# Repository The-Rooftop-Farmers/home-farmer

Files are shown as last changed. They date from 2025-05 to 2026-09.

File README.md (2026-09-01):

# Home Farmer Robot

> **Note:** This file has been modified using AI.

The **Home Farmer Robot** is a semi-automatic plant care robot designed to monitor and maintain optimal growing conditions for small-scale indoor farming. Built for the **World Robot Olympiad (WRO)** competition, this project uses an Arduino-controlled gantry system with sensors and a Raspberry Pi web dashboard to automate irrigation, seeding, and environmental monitoring.

> 🌐 **Live Website:** [the-rooftop-farmers.github.io/home-farmer](https://the-rooftop-farmers.github.io/home-farmer)
>
> 📦 **Required Library:** [Operate Library](https://github.com/The-Rooftop-Farmers/Operate-Lib/releases) — install via Arduino IDE (Sketch → Include Library → Add .ZIP Library)

---

## Features

- **3-Axis Gantry System** — X/Y/Z stepper motors with limit-switch homing and position limits (via [Operate Library](https://github.com/The-Rooftop-Farmers/Operate-Lib))
- **Automated Seeding** — Picks seeds from a designated area and plants at 4 predefined positions (or custom coordinates via rotary encoder)
- **Smart Watering** — Measures soil moisture at each plant; waters only when below threshold (40%), re-checks until target (70%) reached
- **Environmental Monitoring** — DHT11 temperature/humidity + soil moisture sensor (analog)
- **Real-Time Clock** — DS1307 RTC for scheduled auto-watering (3 min interval, configurable)
- **LCD Menu Interface** — 20×4 I²C LCD with rotary encoder + button navigation
- **Raspberry Pi Web Dashboard** — Live camera feed (Pi Camera 2), sensor charts (Chart.js), REST API (`/sensors`, `/sensors/history`, `/video`)
- **Alexa/Serial Integration** — Accepts `SEED`, `WATER`, `RESET`, `DHT:` commands over serial
- **Auto-Watering Mode** — Background timer triggers watering cycle independently of menu

---

## Hardware

| Component | Qty | Notes |
|---|-----|---|
| Arduino Mega 2560 (or Uno with port expanders) | 1 | Main controller |
| NEMA 17 Stepper Motors | 3 | X, Y, Z axes |
| A4988 / DRV8825 Stepper Drivers | 3 | One per motor |
| Limit Switches (NO) | 3 | Homing for X, Y, Z |
| Soil Moisture Sensor (capacitive/resistive) | 1 | Analog, connected to A3 |
| DHT11 Temperature/Humidity Sensor | 1 | Digital, pin 27 on Pi (also read via serial from Arduino) |
| DS1307 RTC Module | 1 | I²C (0x68) |
| 20×4 I²C LCD (0x27) | 1 | 4-row display |
| Rotary Encoder (KY-040) | 1 | CLK=A2, DT=A1, SW=A0 |
| Water Pump (5V/12V) + Relay/Transistor | 1 | Pin 12 (Arduino) |
| Servo (SG90/MG996R) | 1 | Seed picker, pin 13 |
| Raspberry Pi 4 + Pi Camera Module 2 | 1 | Web dashboard + camera |
| 3D Printed Frame & Gantry | 1 | See `3D Printing/` |

---

## Pinout (Arduino)

| Function | Pin | Notes |
|---|-----|---|
| Stepper X – Step | 2 | `mot_x.setPin(2, 5)` |
| Stepper X – Dir | 5 | |
| Stepper Y – Step | 3 | `mot_y.setPin(3, 6)` |
| Stepper Y – Dir | 6 | |
| Stepper Z – Step | 4 | `mot_z.setPin(4, 7)` |
| Stepper Z – Dir | 7 | |
| Limit Switch X | 9 | `INPUT_PULLUP` |
| Limit Switch Y | 10 | `INPUT_PULLUP` |
| Limit Switch Z | 11 | `INPUT_PULLUP` |
| Water Pump Relay | 12 | `OUTPUT`, active HIGH |
| Servo (Seed Picker) | 13 | `Servo.attach(13)` |
| Soil Moisture (Analog) | A3 | 0–1023 → mapped to 0–100% |
| Rotary Encoder CLK | A2 | |
| Rotary Encoder DT | A1 | |
| Rotary Encoder SW | A0 | `INPUT_PULLUP` (button) |
| I²C SDA/SCL | 20/21 | LCD (0x27), RTC (0x68) |

---

## Software Architecture

```
┌─────────────────────────────────────────────────────────────┐
│                      ARDUINO (main.ino)                      │
│  ┌──────────────┐ ┌──────────────┐ ┌────────────────────┐  │
│  │ Gantry Control│ │ Sensor Read  │ │ Menu State Machine │  │
│  │ (Operate lib) │ │ (DHT, Moist, │ │ (20 screens, rotary │  │
│  │  Homing, Limits)│ │  RTC)      │ │  encoder + button) │  │
│  └──────┬───────┘ └──────┬───────┘ └─────────┬──────────┘  │
│         │                │                   │             │
│         └────────────────┼───────────────────┘             │
│                          ▼                                  │
│                   Serial (9600) ◄──────────────────────┐    │
└──────────────────────────────────────────────────────────│────┘
                                                           │ USB
                                                           ▼
┌──────────────────────────────────────────────────────────────────┐
│                    RASPBERRY PI (Flask + PiCamera2)               │
│  ┌─────────────┐  ┌─────────────┐  ┌─────────────────────────┐  │
│  │ Serial Bridge│  │ Sensor Sampler│ │   Web Routes (Flask)    │  │
│  │ (MOISTURE:←  │  │ (1 Hz, DHT +  │  │  /          → index.html│  │
│  │  DHT:→)      │  │  Arduino)    │  │  /video     → MJPEG     │  │
│  └─────────────┘  └─────────────┘  │  /sensors   → JSON now    │  │
│                                    │  /sensors/history → JSON  │  │
│                                    └─────────────────────────┘  │
└──────────────────────────────────────────────────────────────────┘
```

**Key Data Flow:**
1. Arduino reads soil moisture (A3) → sends `MOISTURE:<val>\n` every 1 s
2. Pi reads serial, parses moisture, updates global `soil_moisture_value`
3. Pi reads DHT11 locally → sends `DHT:<temp>,<hum>\n` back to Arduino (Arduino displays on LCD)
4. Flask serves `/sensors` (current), `/sensors/history` (last 60 samples), `/video` (MJPEG stream)

---

## Getting Started

### 1. Arduino Firmware

**Dependencies (Arduino IDE → Library Manager):**
- `Operate` — [download ZIP](https://github.com/The-Rooftop-Farmers/Operate-Lib/releases) → Sketch → Include Library → Add .ZIP Library
- `LiquidCrystal_I2C`
- `uRTCLib`
- `DHT sensor library` (Adafruit)
- `Servo` (built-in)

**Upload:**
1. Open `main/main.ino`
2. Select board (Arduino Mega 2560) and port
3. Upload

**Calibration (adjust in code):**
- `xStepsPerCm`, `yStepsPerCm` in `UnitConversion()` — measure your gantry travel per step
- `xOffset`, `halfSquareWidth` — physical offsets
- Soil moisture `map()` ranges (lines 350, 448) — measure dry/wet raw values
- Motor speeds (`setSpeed`), homing speeds, position limits — match your hardware

### 2. Raspberry Pi Dashboard

**Requirements:**
- Raspberry Pi OS (64-bit recommended)
- Python 3.9+
- Pi Camera Module 2 (or USB webcam — modify `main.py`)

**Install:**
```bash
cd "Raspberry Pi Scripts/Web Dashboard"
python3 -m venv .venv
source .venv/bin/activate
pip install -r requirements.txt
# requirements.txt: flask, pyserial, opencv-python, picamera2, Adafruit-DHT
```

**Run:**
```bash
python main.py
# Serves on http://<pi-ip>:4000
```

**Systemd Service (auto-start):**
```ini
# /etc/systemd/system/home-farmer-dashboard.service
[Unit]
Description=Home Farmer Web Dashboard
After=network.target

[Service]
WorkingDirectory=/home/pi/HomeFarmer/Raspberry Pi Scripts/Web Dashboard
ExecStart=/home/pi/HomeFarmer/Raspberry Pi Scripts/Web Dashboard/.venv/bin/python main.py
Restart=always
User=pi

[Install]
WantedBy=multi-user.target
```
```bash
sudo systemctl enable --now home-farmer-dashboard
```

### 3. 3D Printing

STL files in `3D Printing/2024 (v2.4)/Home Farmer All 3D Printed Parts.stl`. Print with:
- Material: PLA or PETG
- Infill: 30–40% (structural parts), 15% (non-structural)
- Layer height: 0.2 mm
- Supports: As needed for overhangs

---

## Menu System (LCD)

| Screen | Function |
|---|---|
| 0/1 | Home — time, date, temp, humidity, menu entry |
| 3 | Info — version, authors, mentor |
| 4 | Main Menu — Plant Seed / Water Plants / Parameters / Exit |
| 5–6 | Plant Seed confirmation |
| 7–11 | Water Plants / Parameters / Exit navigation |
| 12–14 | Seed planting confirmation (Yes/No) |
| 15 | Seeding in progress (homes → seeds 4 positions → homes) |
| 16–18 | Watering confirmation (Yes/No) |
| 19 | Watering in progress (homes → checks 4 positions → homes) |
| 20 | Parameters — live temp/humidity/moisture display |

**Navigation:** Rotary encoder scrolls, button selects. `>` indicator shows cursor.

---

## Serial Commands (for Alexa / Home Assistant / Custom Integrations)

Send via USB serial (9600 baud, newline-terminated):

| Command | Effect |
|---|---|
| `SEED` | Homes all axes, runs seeding sequence (screen 15) |
| `WATER` | Homes all axes, runs watering sequence (screen 19) |
| `RESET` | Software reset (watchdog) |
| `DHT:<temp>,<hum>` | Pi → Arduino: updates displayed temp/humidity |

Example (Python):
```python
import serial
ser = serial.Serial('/dev/ttyACM0', 9600, timeout=1)
ser.write(b'SEED\n')
```

---

## Project Structure

```
Home Farmer/
├── main/
│   └── main.ino              # Arduino firmware (1200+ lines)
├── Raspberry Pi Scripts/
│   └── Web Dashboard/
│       ├── main.py           # Flask + PiCamera2 + serial bridge
│       ├── requirements.txt
│       ├── templates/
│       │   └── index.html    # Dashboard UI (Chart.js)
│       └── static/
│           ├── style.css
│           └── script.js     # Live sensor charts
├── 3D Printing/
│   └── 2024 (v2.4)/
│       └── Home Farmer All 3D Printed Parts.stl
├── Old Code/                 # Early prototypes (reference only)
├── Project Reports/          # WRO competition reports (PDF)
└── README.md                 # This file
```

---

## Troubleshooting

| Symptom | Likely Cause | Fix |
|---|---|-----|
| Motors don't home | Limit switch wiring / `INPUT_PULLUP` logic | Check switches: NO → pin reads LOW when triggered |
| Soil moisture always 0/100 | `map()` range wrong | Measure raw `analogRead(A3)` in air vs water; update `map(min, max, 0, 100)` |
| LCD shows garbage | I²C address wrong | Run I²C scanner; common addresses: 0x27, 0x3F |
| Pi dashboard shows no camera | `picamera2` not configured | `sudo raspi-config` → Interface Options → Camera → Enable |
| Serial `MOISTURE:` not received | Baud mismatch / port wrong | Confirm 9600 baud; `ls /dev/ttyACM*` or `ttyUSB*` |
| Auto-watering doesn't trigger | `autowater` flag false | Set `bool autowater = true;` in code or via menu (not yet exposed) |

---

## Competition History

- **WRO 2024 (v2.4)** — Virtual & Regional rounds — Project reports in `Project Reports/2024/` and `2025/`
- **Team:** The Rooftop Farmers
- **Students:** Vihaan Parlikar, Yogeshwar Deshmukh
- **Mentor:** Malhar Ashtaputre

---

## License

MIT License — see [LICENSE](LICENSE).

---

## Acknowledgements

- [Operate Library](https://github.com/The-Rooftop-Farmers/Operate-Lib) — Stepper motor control with homing/limits
- Original Foliate project (inspiration for modular design)
- World Robot Olympiad community

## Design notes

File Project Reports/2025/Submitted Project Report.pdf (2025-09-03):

# HOME

# WRO Junior Future Innovators

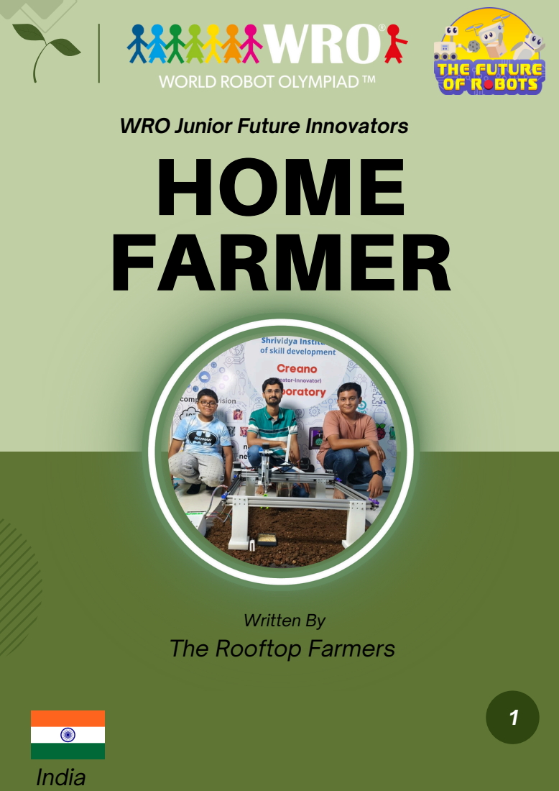
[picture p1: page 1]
FARMER; India

Written By
The Rooftop Farmers

# WRO Junior Future Innovators

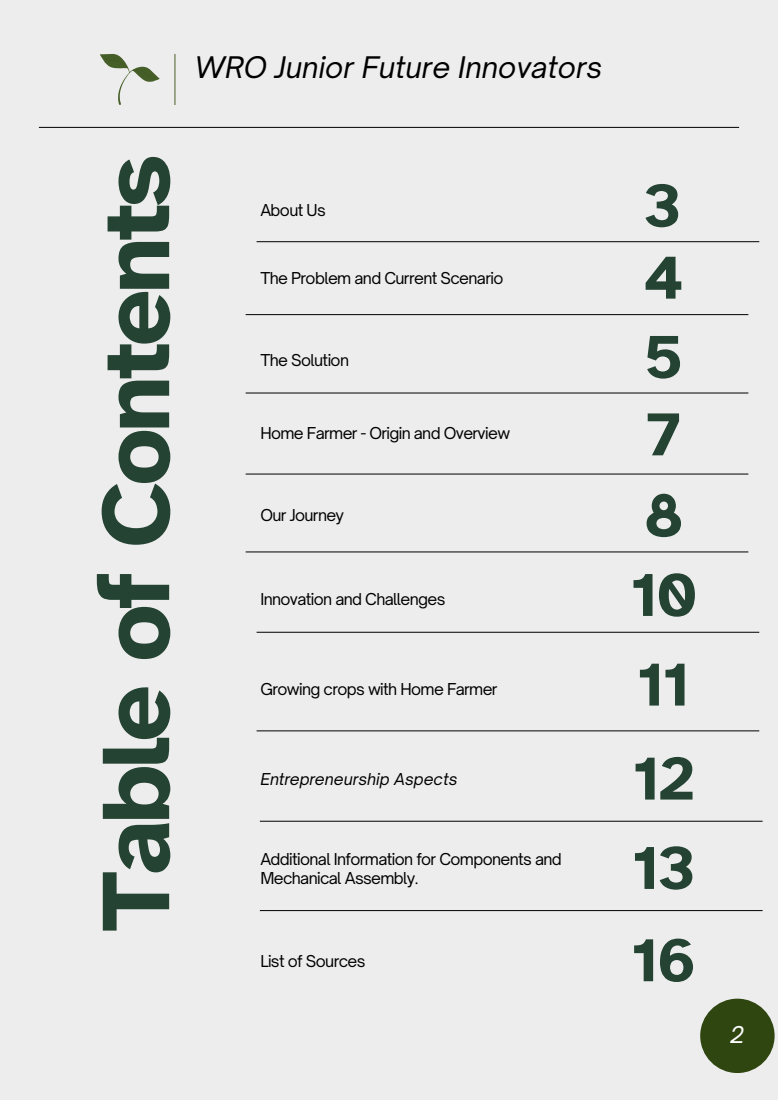
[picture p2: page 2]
About Us; The Problem and Current Scenario; The Solution; Home Farmer - Origin and Overview; Our Journey; Innovation and Challenges; Mechanical Assembly.; Entrepreneurship Aspects

Growing crops with Home Farmer

Additional Information for Components and

List of Sources

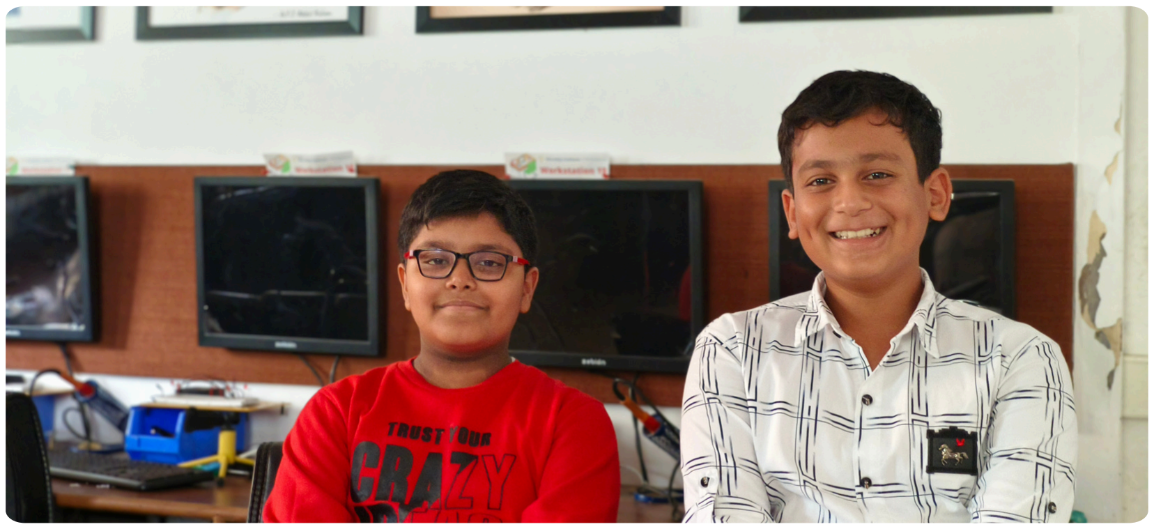
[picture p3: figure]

The Rooftop Farmers, a duo of school students, are on a mission to revolutionize sustainable development through robotics. With a keen interest in environmental conservation, they're making innovative solutions that promise a greener future. These two young minds are tirelessly developing a sustainable robotics project, aiming to safeguard the environment and promote eco-friendly practices. Their dedication, creativity, and passion for sustainability make them a force to be reckoned with, embodying the spirit of youth-driven change in the quest

Picture 1 - Yogeshwar & Vihaan

# ABOUT US

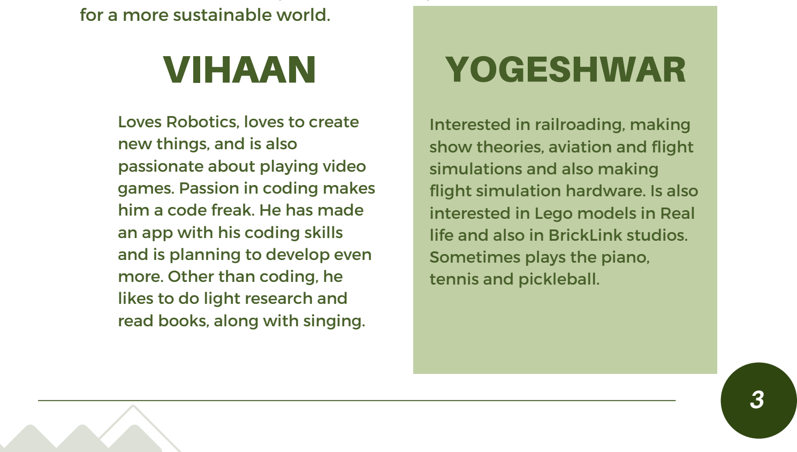
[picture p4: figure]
for a more sustainable world.; Loves Robotics, loves to create new things, and is also passionate about playing video games. Passion in coding makes him a code freak. He has made an app with his coding skills and is planning to develop even more. Other than coding, he likes to do light research and read books, along with singing.; Interested in railroading, making show theories, aviation and flight simulations and also making flight simulation hardware. Is also interested in Lego models in Real life and also in BrickLink studios. Sometimes plays the piano, tennis and pickleball.; VIHAAN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

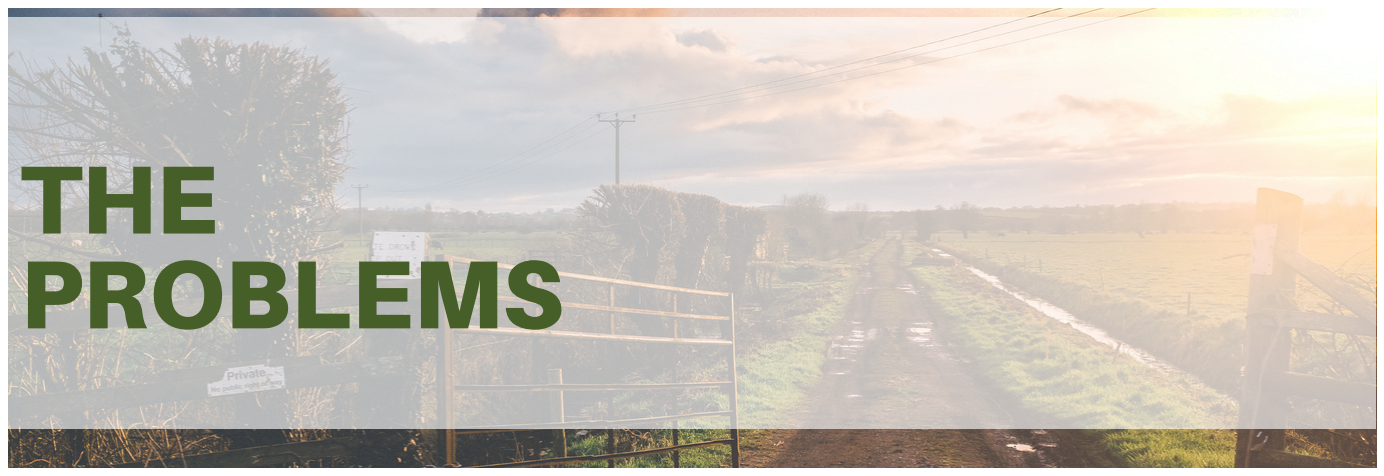
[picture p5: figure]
THE PROBLEMS

The current scene regarding land pollution and soil infertility paints a concerning picture of environmental degradation. As the population grew, farmers started using chemical fertilizers to meet demands. This rampant use of chemical fertilizers has led to soil degradation, reduced fertility, and contamination of groundwater. These practices not only harm the soil but also affect the quality of our food supply. Excessive use of fertilizers contributes to nutrient imbalances in crops, leading to health issues like diseases of the kidneys and liver, and certain cancers in consumers. These adverse effects not only endanger public health but also hinder sustainable development by compromising the long-term viability of agricultural systems and ecosystems, emphasizing the urgent need for eco-friendly farming practices.

## A Brief Description About the Current Scenario

## The Global Warming Effect

Urban food production is challenging due to limited space and busy lifestyles, making traditional gardening difficult.

” The problem matters as
cities face a growing demand for sustainable, self-reliant food production.

## The Urban Challenge

Global warming makes land pollution and soil problems worse. It changes rain and causes droughts or floods, harming soil.

“High
temperatures accelerate soil degradation, making food production more difficult and affecting health and sustainable development. We need to act fast to fix this.

4

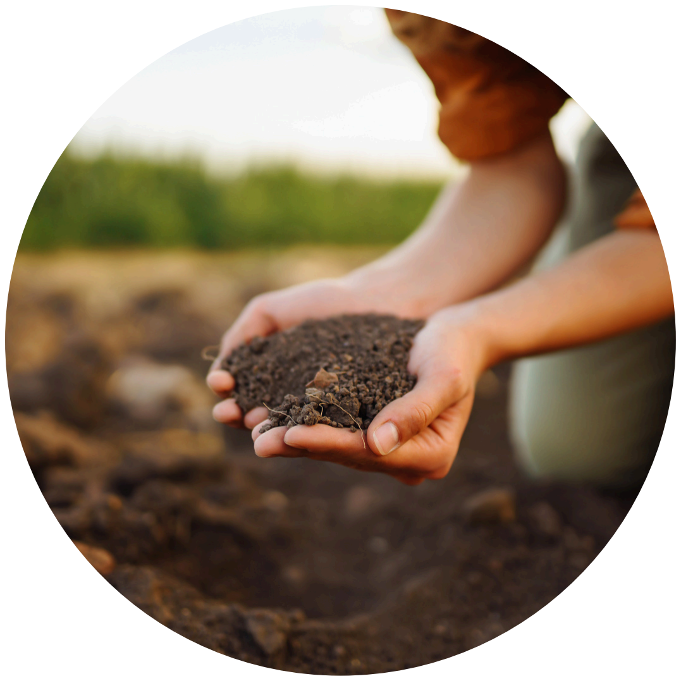
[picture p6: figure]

# THE SOLUTION

Our project, Home Farmer, aims to address the pressing issues of produce being grown with chemical fertilizers, and the growing need for sustainable urban farming. These challenges are critical due to their impact on food safety, environmental health, and sustainable development. Though “Very few people practice home farming because growing organic food at home is challenging and time-consuming.

”
Home farming is uncommon as people find it difficult to produce truly organic food without using chemical fertilizers.

”

## Problem Statement:

We chose this problem because conventional farming practices often contribute to soil degradation and pollution through the heavy use of chemical fertilizers, pesticides, and intensive land cultivation. Urbanization further exacerbates these issues by reducing available arable land and increasing pollution levels.

## Why This Problem

Home Farmer is the robotic solution that we designed to revolutionize farming practices. It is capable of planting seeds, autonomously providing daily water requirements, and monitoring the environment in which the plants are growing. By incorporating sensors and sustainable farming techniques, Home Farmer optimizes resource usage and reduces reliance on harmful chemicals. The solution also reduces the human efforts for farming and makes it easily available at home.

## Robotic Solution

5

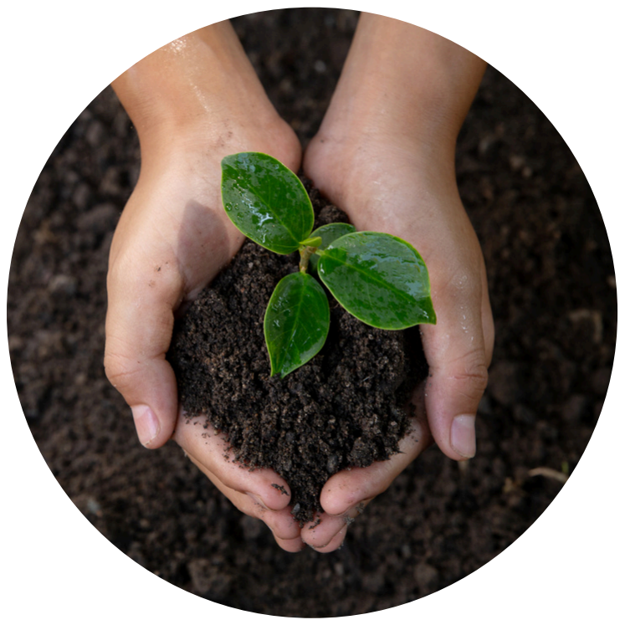
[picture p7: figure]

# THE SOLUTION

The implementation of Home Farmer in real-life scenarios offers immense value. It conserves water through precise irrigation, eliminates the need for chemical fertilizers, and promotes healthy plant growth. This not only improves crop yields but also enhances the quality of the plants. Furthermore, Home Farmer enables efficient urban farming, making it possible to produce fresh, healthy food. By dedicating minimal time to farming, individuals can enjoy freshly grown plants without the use of fertilizers, all conveniently at their doorstep. This is achievable without disrupting their daily schedules, work commitments, or leisure time, thanks to our home farmer

## Value of the Robotic Solution

Home Farmer is crucial in addressing global challenges related to food production, environmental sustainability, and urban development. By promoting sustainable farming practices, reducing pollution, and conserving natural resources, our project contributes to building resilient agricultural systems and ensures a healthier future for both people and the planet.

## Importance of the Project

6

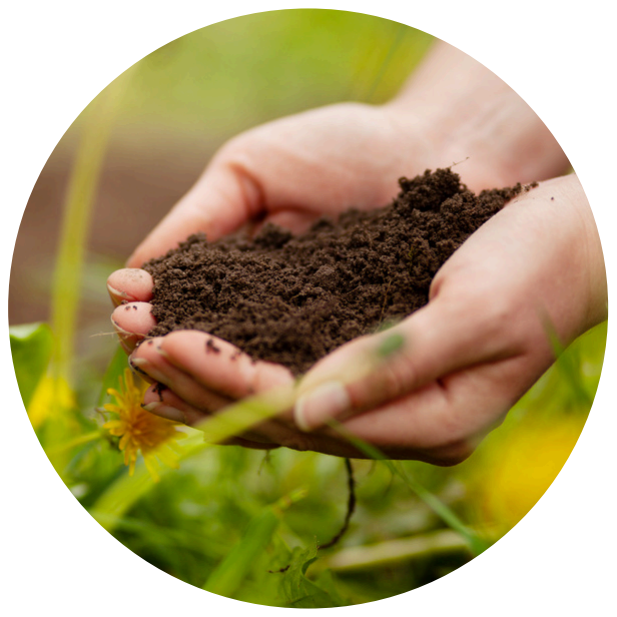
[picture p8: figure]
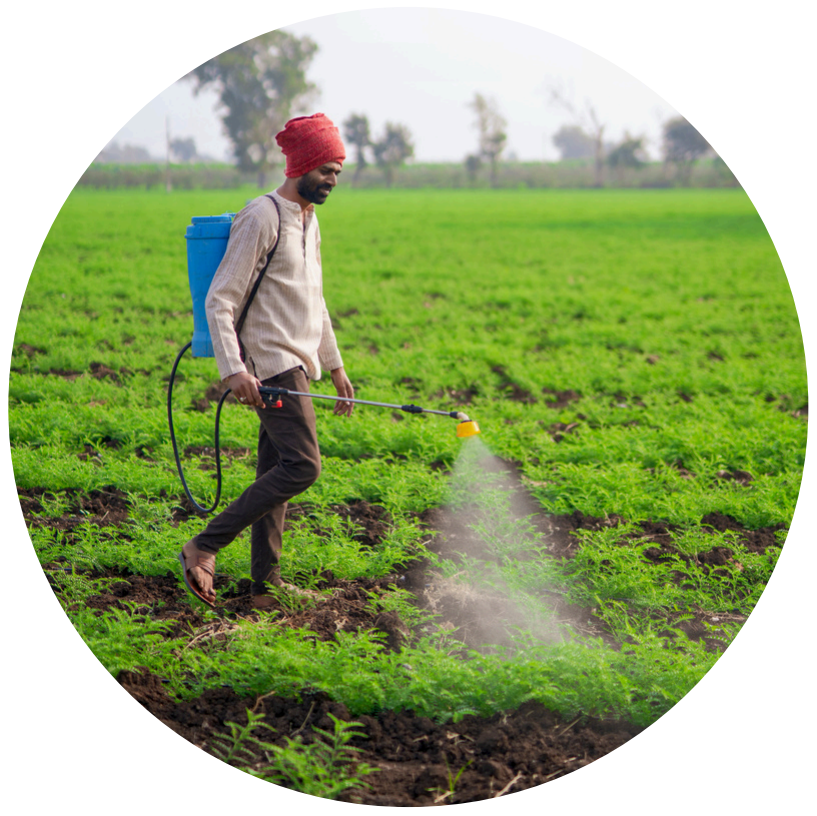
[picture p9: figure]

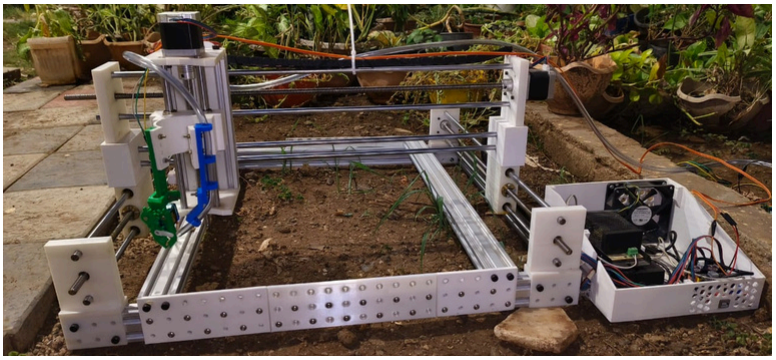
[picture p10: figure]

To empower individuals with the tools and knowledge to cultivate their own food at home, we harness
accessible | and | innovative
technology. Our aim is to foster sustainability and self-sufficiency,
guiding | individuals | towards
healthier | lifestyles | and
environmental stewardship.

Picture 1.2 - Home Farmer V1

# HOME FARMER

Origins of the Idea: The concept of Home Farmer emerged from our deep concern about the environmental impact of traditional farming methods and the challenges posed by urbanization on agricultural practices. We recognized the need for a sustainable solution that could address soil degradation, land pollution, and the growing demand for urban farming.

Our project revolves around the development of a Home Farming Robot, a sophisticated yet user-friendly system designed to enable individuals to grow their own food at home autonomously. Leveraging cutting-edge technology such as robotics, automation, and sensor integration, the Home Farming Robot streamlines the process of home gardening, making it accessible to people of all skill levels.

# OUR MISSION OVERVIEW

Although established farming techniques exist, it's surprising that home farming isn't more popular. This is especially concerning given the harmful effects of pesticides on daily consumed crops. To tackle this issue, we came up with a simple and cost-effective solution – introducing Home Farmer.

7

# OUR JOURNEY

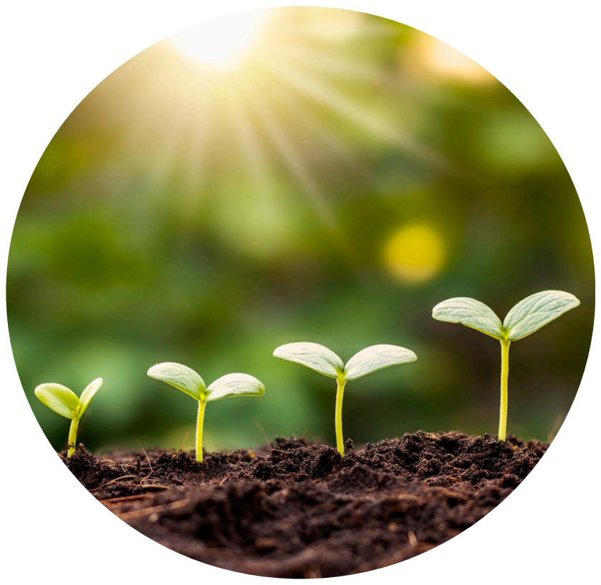
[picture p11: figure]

## How we got the idea for our solution

When we found a pricey commercial farming robot meant for home, we liked its features but couldn't afford it. So, we decided to make our own version which can be used in homes. We wanted something cheaper and easier for home use. By taking ideas from the expensive one and simplifying them, we aimed to create a friendly and affordable system for home farming.

3D printed parts provide structural support and secure aluminum profiles.
Aluminum profiles provide horizontal support.
Belt and trolley provide movement for X and Y axes. Allen bolts connect aluminum profiles to 3D printed parts. Linear bearings and lead screw facilitate Z axis movement. Ball bearings reduce rotational friction for Z axis.
Couplers connect stepper motors to pulley.
The belt goes around 1 axis, with the ends connecting to the trolley, which is then moved by the stepper motors. Raspberry pi enables the robot to use the app and the alexa as well as the camera livestream

### Mechanical Construction -

- VV22

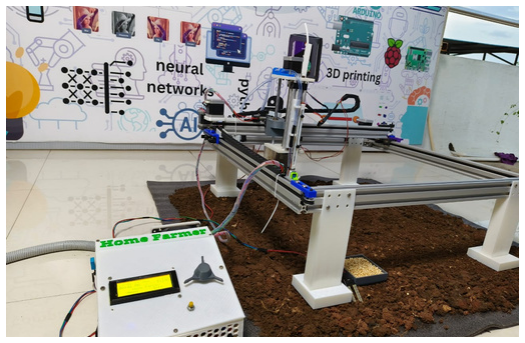
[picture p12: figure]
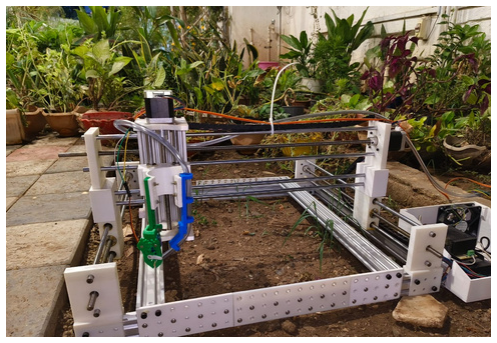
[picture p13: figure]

Picture 1.3 - Home Farmer V1 | Picture 1.4 - Home Farmer V2

8

# OUR JOURNEY - CONTINUED

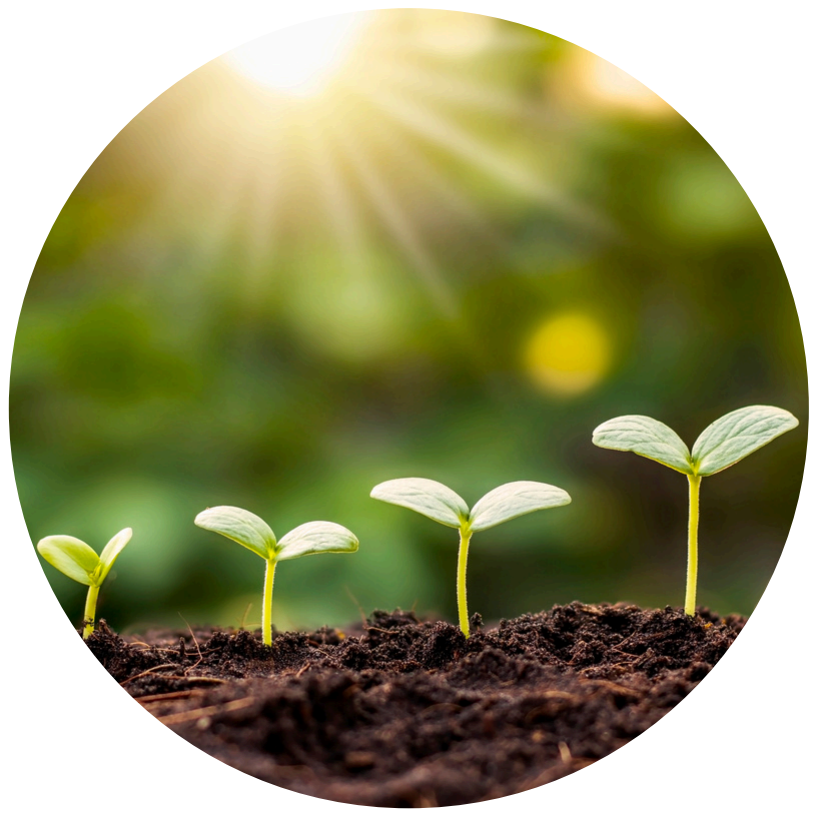
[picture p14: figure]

The code automates movement with stepper motors and a servo, looping through predefined actions based on the XY-coordinate system. It's part of a robotics or automation project, requiring precise motor control. Additionally, it features a 20x4 LCD for real-time updates on the bot's function and seeding recommendations, with a switch for watering plants. This indicates its integration into a formalized project, possibly in robotics or automation, demanding meticulous motor control for synchronized operations.

## Coding of the Solution

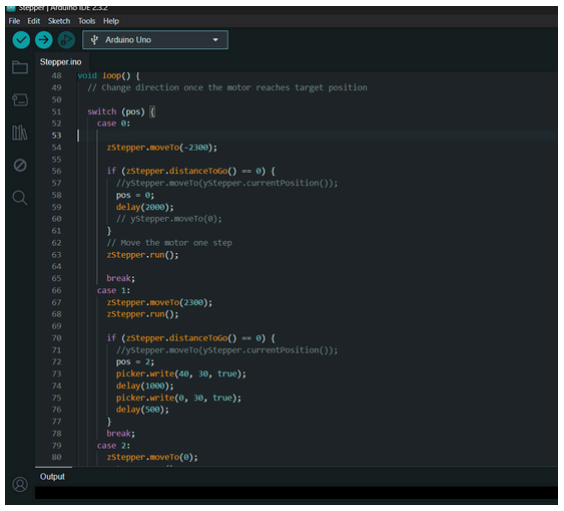
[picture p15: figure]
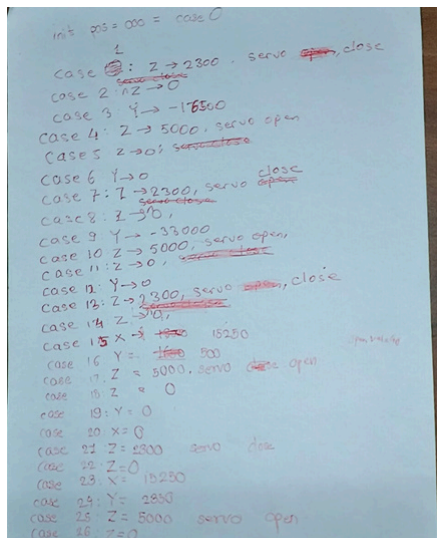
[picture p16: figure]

The Home Farmer robot helps everyone grow fresh, healthy vegetables right at home, even in small spaces like apartments. This means people get organic, chemical-free food, reducing the need for harmful pesticides and fertilizers that damage our soil and water. By using Home Farmer, we promote healthier eating habits and protect our environment from pollution. It also encourages families and kids to learn about farming and caring for our planet. With Home Farmer, we can make our world greener and healthier, one home at a time, while making farming easy and fun for everyone!

## Social Impact of the Product

Scribble of
initial
code

9

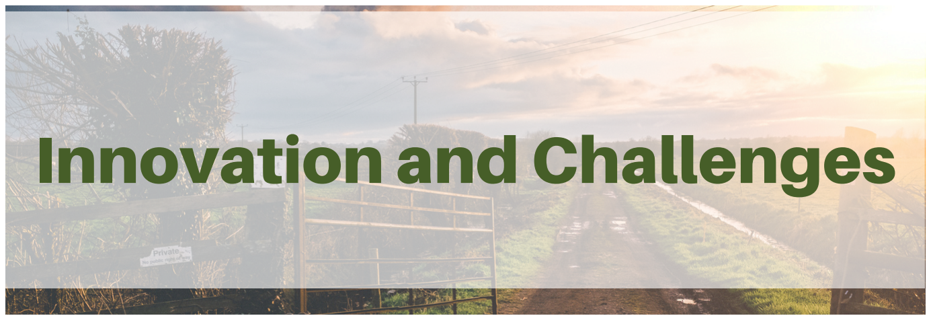
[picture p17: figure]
Innovation and Challenges

First – Affordability: We use 3D printing and simple components to cost much less than commercial alternatives.
Second – Educational Value: Home Farmer turns any home into a learning lab where families can learn about sustainable farming and healthy eating firsthand.
Third – User-Friendly: Simple design with smart sensors means minimal maintenance – meaning that even people with no gardening experience can grow fresh food!
Fourth - Speed: We have worked on replacing the lead screw model with a faster, more efficient belt drive model.
Fifth - Quality of Life: With its voice assistant and simple to use interface, Home Farmer helps even the people who have little to no gardening experience to grow their own food

10

## Home Farmer is made special by 5 key innovations

## During the construction of our robotic solution we faced

many challenges. These included.....

The pump was not able to function properly and pump enough water for some time
Problems with connecting the temperature sensor to the Raspberry Pi instead of the Arduino
During the Alexa based planting testing we faced challenges to get it to connect to the raspberry pi
The pulleys being too loose making the axis move get jammed.

# Growing crops using Home Farmer

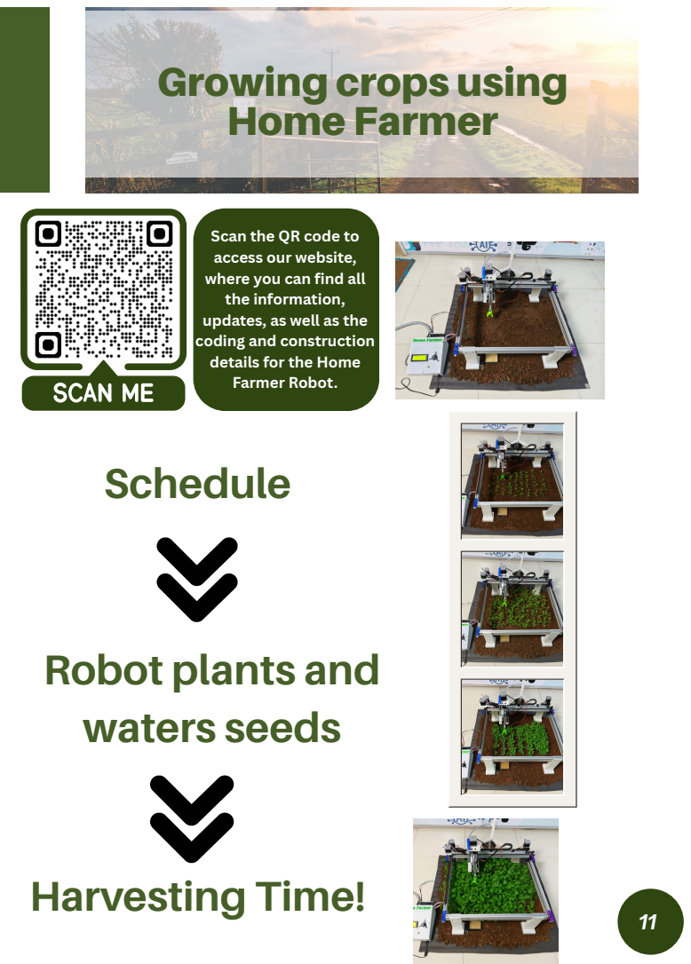
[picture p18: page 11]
Harvesting Time!

Scan the QR code to
access our website,
where you can find all
the information,
updates, as well as the
coding and construction
details for the Home
Farmer Robot.
Schedule

Robot plants and
waters seeds

# Entrepreneurship Aspect

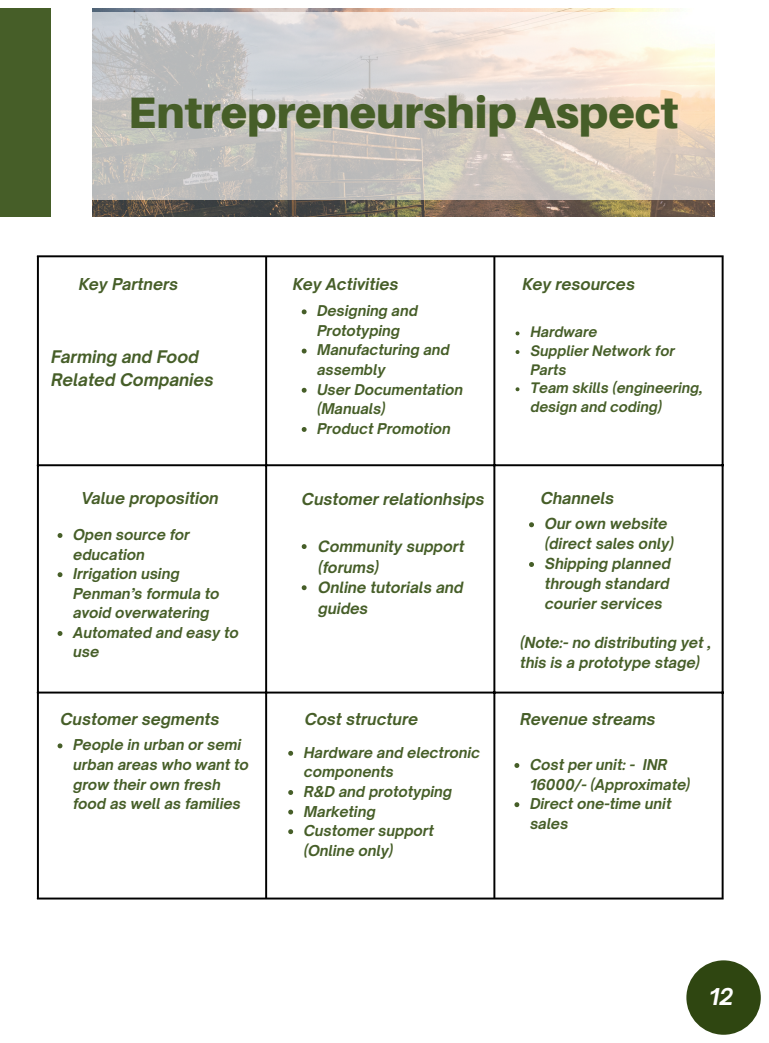
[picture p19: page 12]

Key Partners Farming and Food Related Companies | Key Activities Designing and Prototyping Manufacturing and assembly User Documentation (Manuals) Product Promotion | Key resources Hardware Supplier Network for Parts Team skills (engineering, design and coding)

Value proposition Open source for education Irrigation using Penman’s formula to avoid overwatering Automated and easy to use | Customer relationhsips Community support (forums) Online tutorials and guides | Channels Our own website (direct sales only) Shipping planned through standard courier services (Note:- no distributing yet , this is a prototype stage)

Customer segments People in urban or semi urban areas who want to grow their own fresh food as well as families | Cost structure Hardware and electronic components R&D and prototyping Marketing Customer support (Online only) | Revenue streams Cost per unit: - INR 16000/- (Approximate) Direct one-time unit sales

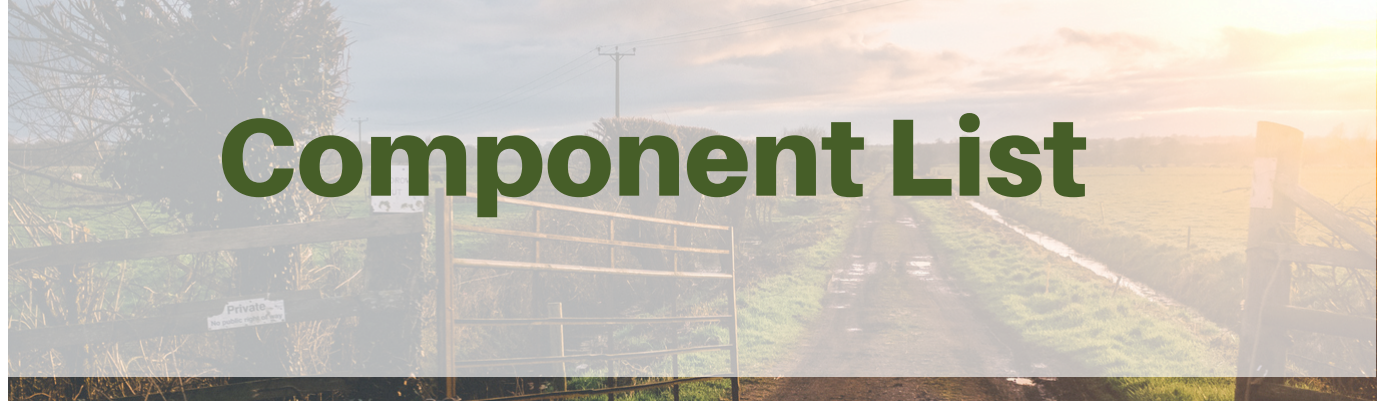
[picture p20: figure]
Component List

Component | Quantity | Usage of Component
DS1307 RTC | 1 | For Time display on LCD
20x4 I2C LCD | 1 | For Display of Menu, features, and for selection of action
Arduino UNO | 1 | Arduino UNO specifically to host the CNC Shield V3
CNC Shield V3 | 1 | To host the Stepper Motor drivers needed
DRV 8825 Stepper Motor Driver | 4 | For Proper functioning of Stepper Motors
NEMA 17 Stepper Motor | 4 | 2 for movement of x axis, 1 for y axis, and 1 for z axis.
Raspberry Pi | 1 | To connect the Arduino to Alexa, and the Web Dashboard.
DHT11 | 1 | To measure the humidity and temperature of surrounding
Soil Moisture Sensor | 1 | To measure soil moisture for plant health
Encoder | 1 | For user input to select an action on LCD
Switch | 1 | Reset Button for emergency stop or homing
Fan (12v) | 1 | To cool the DRV8825 Stepper motor driver
Servo Motor (180 Degrees) | 1 | To pick up the seeds and plant them
Water Pump | 1 | 13 To water the plants when called for

# Components - Additional Information

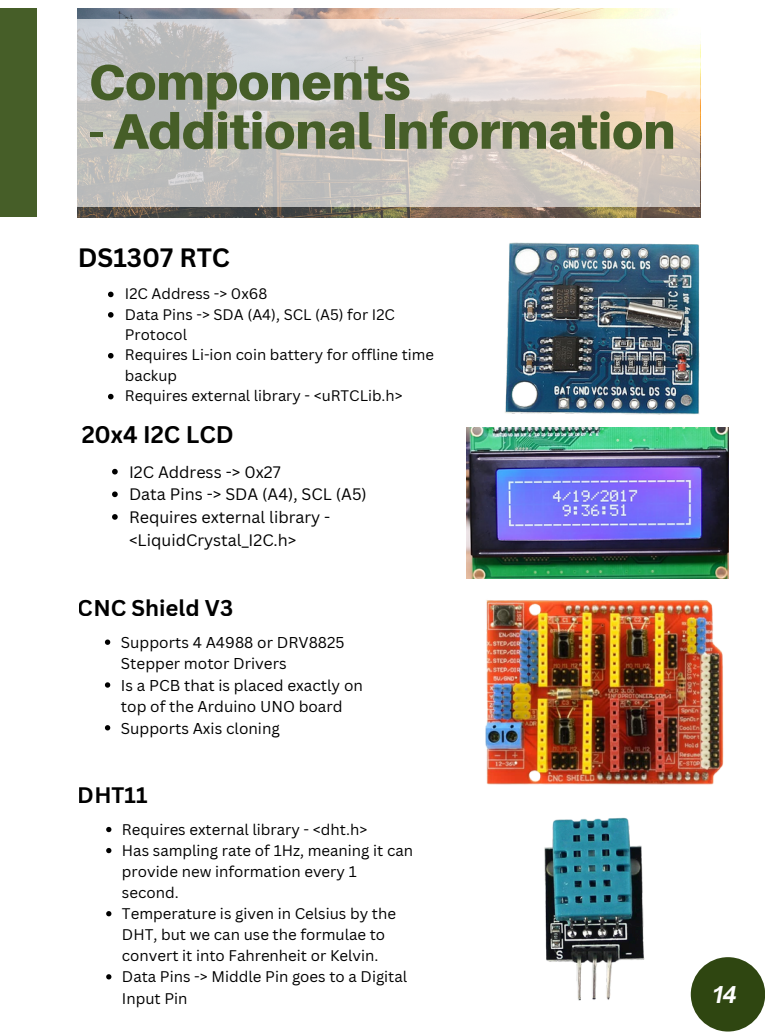
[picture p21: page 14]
DS1307 RTC; CNC Shield V3; DHT11

I2C Address -> 0x68
Data Pins -> SDA (A4), SCL (A5) for I2C
Protocol
Requires Li-ion coin battery for offline time
backup
Requires external library - <uRTCLib.h>
20x4 I2C LCD

I2C Address -> 0x27
Data Pins -> SDA (A4), SCL (A5)
Requires external library -
<LiquidCrystal_I2C.h>

Supports 4 A4988 or DRV8825
Stepper motor Drivers
Is a PCB that is placed exactly on
top of the Arduino UNO board
Supports Axis cloning

Requires external library - <dht.h>
Has sampling rate of 1Hz, meaning it can
provide new information every 1
second.
Temperature is given in Celsius by the
DHT, but we can use the formulae to
convert it into Fahrenheit or Kelvin.
Data Pins -> Middle Pin goes to a Digital
Input Pin

# Components - Additional Information

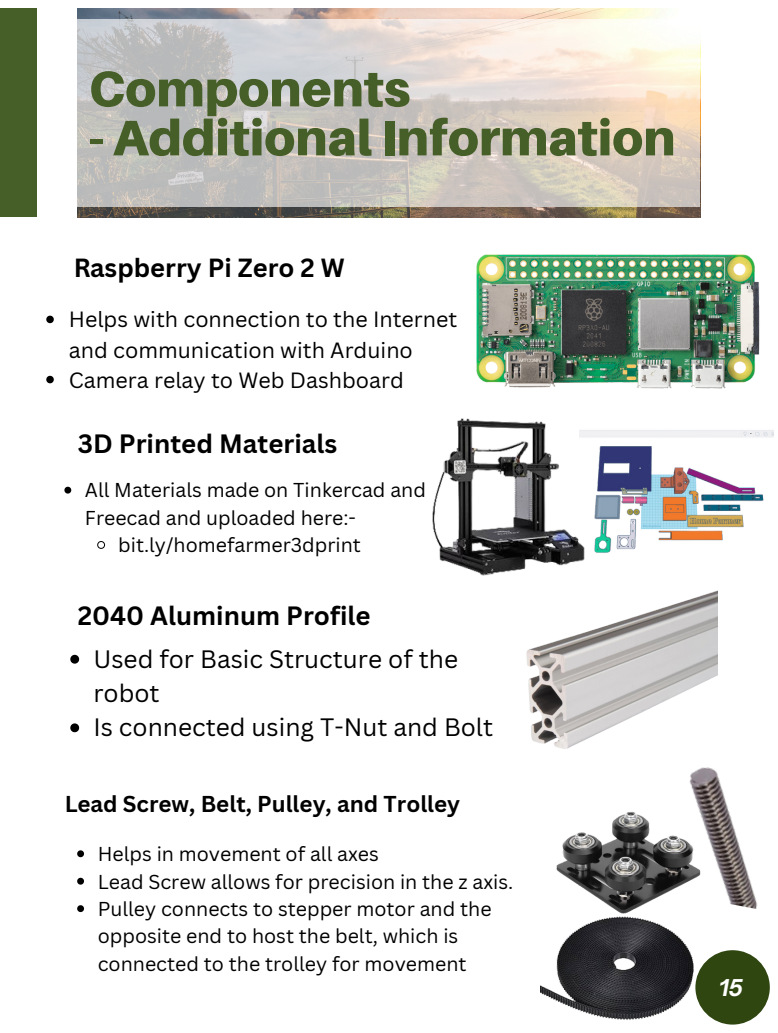
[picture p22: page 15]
3D Printed Materials

Raspberry Pi Zero 2 W

Helps with connection to the Internet
and communication with Arduino
Camera relay to Web Dashboard

All Materials made on Tinkercad and
Freecad and uploaded here:-
bit.ly/homefarmer3dprint

2040 Aluminum Profile
Used for Basic Structure of the
robot
Is connected using T-Nut and Bolt

Lead Screw, Belt, Pulley, and Trolley

Helps in movement of all axes
Lead Screw allows for precision in the z axis.
Pulley connects to stepper motor and the
opposite end to host the belt, which is
connected to the trolley for movement

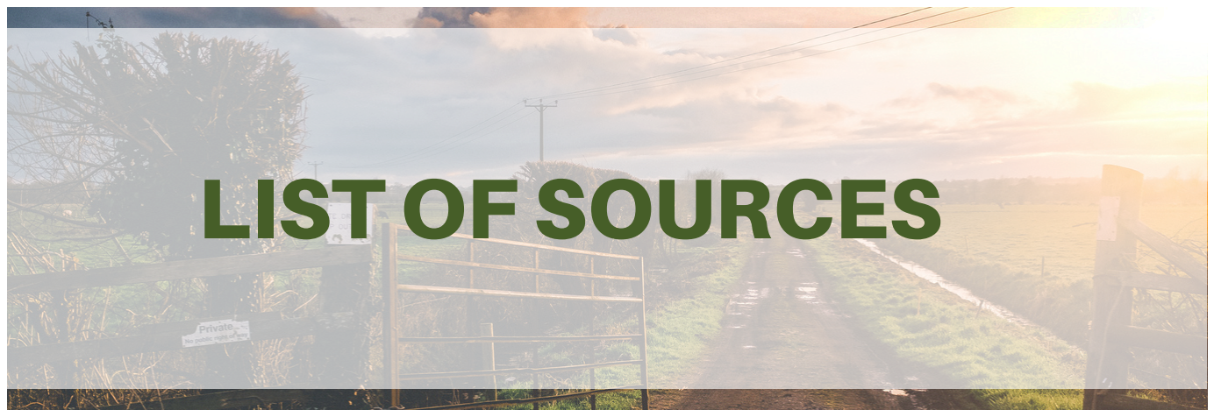
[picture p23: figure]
LIST OF SOURCES

https://lastminuteengineers.com/ds1307-rtc-arduino-tutorial/https://lastminuteengineers.com/arduino-1602-character-lcd-tutorial/https://www.youtube.com/watch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
https://forum.arduino.cc/t/using-cnc-shield-v3-directly-with-arduino-ide/1022999/2https://www.handsontec.com/dataspecs/cnc-3axis-shield.pdfhttps://www.arduino.cc/ref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 - For designing parts

16

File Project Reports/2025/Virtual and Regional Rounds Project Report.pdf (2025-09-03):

# HOME

# WRO Junior Future Innovators

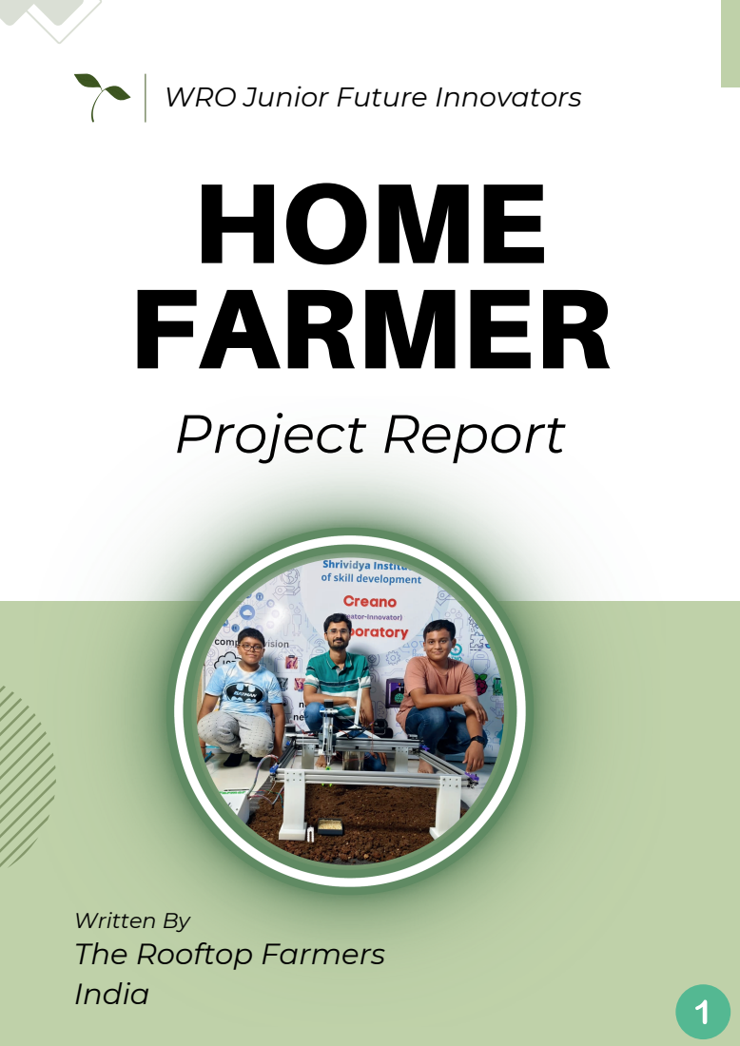
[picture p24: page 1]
FARMER; Project Report

Written By
The Rooftop Farmers
India

# WRO Junior Future Innovators

About Us; The Problem and Current Scenario; The Solution; Home Farmer - Origin and Overview; Our Journey; Components List; List of Sources

Table of Contents

11 Additional Information for Components and
Mechanical Assembly.


The rooftop farmers, a duo of school students, are on a mission to revolutionize sustainable development through robotics. With a keen interest in environmental conservation, they're making innovative solutions that promise a greener future. These two young minds are tirelessly developing a sustainable robotics project, aiming to safeguard the environment and promote eco-friendly practices. Their dedication, creativity, and passion for sustainability make them a force to be reckoned with, embodying the spirit of youth-driven change in the quest

Picture 1 - Yogeshwar & Vihaan

# ABOUT US

for a more sustainable world.; Loves Robotics, loves to create new things, and is also passionate about playing video games. Passion in coding makes him a code freak. He has made a with his coding skills and is planning to develop even more. Other than coding, he likes to do light research and read books, along with singing.; Interested in railroading, making show theories, aviation and flight simulations and also making flight simulation hardware. Is also interested in Lego models in Real life and also in BrickLink studios. Sometimes plays the piano, tennis and pickleball.; VIHAAN; YOGESHWAR

THE PROBLEMS

The current scene regarding land pollution and soil infertility paints a concerning picture of environmental degradation. Rampant use of chemical fertilizers has led to soil degradation, reduced fertility, and contamination of groundwater. These practices not only harm the soil but also affect the quality and safety of our food supply. Excessive use of fertilizers contributes to nutrient imbalances in crops, leading to health issues like diabetes, cardiovascular diseases, and certain cancers in consumers. These adverse effects not only endanger public health but also hinder sustainable development by compromising the long-term viability of agricultural systems and ecosystems, emphasizing the urgent need for eco-friendly farming practices.

## A Brief Description About the Current Scenario

Global warming makes land pollution and soil problems worse. It changes rain and causes droughts or floods, harming soil. The heat also makes soil worse faster. This makes growing food harder and harms health and development. We need to act fast to fix this.

## The Global Warming Effect

The challenge of urban food production, where space constraints and busy lifestyles make traditional gardening difficult. This problem is significant due to the growing need for sustainability and self-sufficiency in food sources within urban environments.

## The Urban Challenge


# THE SOLUTION

Our project, Home Farmer, aims to address the pressing issues of soil degradation, land pollution, and the growing need for sustainable urban farming. These challenges are critical due to their impact on food security, environmental health, and sustainable development. Though home farming is recognized, only a few individuals engage in it, particularly upon realizing the negative impacts of regularly consuming chemically fertilized food. Our robotic solution aims to tackle this issue effectively and ensure sustainable life on land.

## Problem Statement:

We chose this problem because conventional farming practices often contribute to soil degradation and pollution through the heavy use of chemical fertilizers, pesticides, and intensive land cultivation. Urbanization further exacerbates these issues by reducing available arable land and increasing pollution levels.

## Why This Problem

Home Farmer is a cutting-edge robotic solution designed to revolutionize farming practices. It is capable of autonomously planting seeds, nurturing crops, providing daily water requirements, and monitoring plant health. By incorporating sensors and sustainable farming techniques, Home Farmer minimizes soil disturbance, optimizes resource usage, and reduces reliance on harmful chemicals. The solution also reduces the human efforts for farming and makes it easily available at home.

## Robotic Solution

# THE SOLUTION


The implementation of Home Farmer in real-life scenarios offers immense value. It significantly reduces soil erosion, conserves water through precise irrigation, eliminates the need for chemical inputs, and promotes healthy plant growth. This not only improves crop yields but also enhances soil fertility and biodiversity. Furthermore, Home Farmer enables efficient urban farming, making it possible to produce fresh, healthy food. By dedicating minimal time to farming, individuals can enjoy freshly grown plants without the use of fertilizers, all conveniently at their doorstep. This is achievable without disrupting their daily schedules, work commitments, or leisure time, thanks to our Farm bot.

## Value of the Robotic Solution

Home Farmer is crucial in addressing global challenges related to food production, environmental sustainability, and urban development. By promoting sustainable farming practices, reducing pollution, and conserving natural resources, our project contributes to building resilient agricultural systems and ensures a healthier future for both people and the planet.

## Importance of the Project



To empower individuals with the tools and knowledge to cultivate their own food at home, we harness
accessible | and | innovative
technology. Our aim is to foster sustainability and self-sufficiency,
guiding | individuals | towards
healthier | lifestyles | and
environmental stewardship.

Picture 1.2 - Home Farmer V1

# HOME FARMER

Origins of the Idea: The concept of Home Farmer emerged from our deep concern about the environmental impact of traditional farming methods and the challenges posed by urbanization on agricultural practices. We recognized the need for a sustainable solution that could address soil degradation, land pollution, and the growing demand for urban farming.

Our project revolves around the development of a Home Farming Robot, a sophisticated yet user- friendly system designed to enable individuals to grow their own food at home autonomously. Leveraging cutting-edge technology such as robotics, automation, and sensor integration, the Home Farming Robot streamlines the process of home gardening, making it accessible to people of all skill levels.

# OUR MISSION OVERVIEW

Although established farming techniques exist, it's surprising that home farming isn't more popular. This is especially concerning given the harmful effects of pesticides on daily consumed crops. To tackle this issue, we came up with a simple and cost-effective solution – introducing Home Farmer.

# OUR JOURNEY


## How we got the idea for our solution

When we found a pricey commercial farmbot meant for home, we liked its features but couldn't afford it. So, we decided to make our own version which can be used in homes. We wanted something cheaper and easier for home use. By taking ideas from the expensive one and simplifying them, we aimed to create a friendly and affordable system for home farming.

3D printed parts provide structural support and secure aluminum profiles.
Aluminum profiles provide horizontal support.
Belt and trolley provide movement for X and Y axes. Allen bolts connect aluminum profiles to 3D printed parts. Linear bearings and lead screw facilitate Z axis movement. Ball bearings reduce rotational friction for Z axis.
Couplers connect stepper motors to pulley.
The belt goes around 1 axis, with the ends connecting to the trolley, which is then moved by the stepper motors.

### Mechanical Construction - V2


Picture 1.3 - Home Farmer V1 | Picture 1.4 - Home Farmer V2

# OUR JOURNEY - CONTINUED


The code automates movement with stepper motors and a servo, looping through predefined actions based on the XY-coordinate system. It's part of a robotics or automation project, requiring precise motor control. Additionally, it features a 20x4 LCD for real-time updates on the bot's function and seeding recommendations, with a switch for plant watering. This indicates its integration into a formalized project, possibly in robotics or automation, demanding meticulous motor control for synchronized operations.

## Coding of the Solution


The Home Farmer robot helps everyone grow fresh, healthy vegetables right at home, even in small spaces like apartments. This means people get safe, chemical-free food, reducing the need for harmful pesticides and fertilizers that damage our soil and water. By using Home Farmer, we promote healthier eating habits and protect our environment from pollution. It also encourages families and kids to learn about farming and caring for our planet. With Home Farmer, we can make our world greener and healthier, one home at a time, while making farming easy and fun for everyone!

## Social Impact of the Product

Scribble of
initial
code

Component List

Component | Quantity | Usage of Component
DS1307 RTC | 1 | For Time display on LCD
20x4 I2C LCD | 1 | For Display of Menu, features, and for selection of action
Arduino UNO | 1 | Arduino UNO specifically to host the CNC Shield V3
CNC Shield V3 | 1 | To host the Stepper Motor drivers needed
DRV 8825 Stepper Motor Driver | 4 For Proper functioning of Stepper Motors
NEMA 17 Stepper Motor | 4 | 2 for movement of x axis, 1 for y axis, and 1 for z axis.
DHT11 | 1 | To measure the humidity and temperature of surrounding
Soil Moisture Sensor | 1 | To measure soil moisture for plant health
Encoder | 1 | For user input to select an action on LCD
Switch | 1 | Reset Button for emergency stop or homing
Fan (12v) | 1 | To cool the DRV8825 Stepper motor driver
Servo Motor (180 Degrees) | 1 | To pick up the seeds and plant them
Water Pump | 1 | To water the plants when called for

# Components - Additional Information

DS1307 RTC; CNC Shield V3; DHT11

I2C Address -> 0x68
Data Pins -> SDA (A4), SCL (A5) for I2C
Protocol
Requires Li-ion coin battery for offline time
backup
Requires external library - <uRTCLib.h>
20x4 I2C LCD

I2C Address -> 0x27
Data Pins -> SDA (A4), SCL (A5)
Requires external library -
<LiquidCrystal_I2C.h>

Supports 4 A4988 or DRV8825
Stepper motor Drivers
Is a PCB that is placed exactly on
top of the Arduino UNO board
Supports Axis cloning

Requires external library - <dht.h>
Has sampling rate of 1Hz, meaning it can
provide new information every 1
second.
Temperature is given in Celsius by the
DHT, but we can use the formulae to
convert it into Fahrenheit or Kelvin.
Data Pins -> Middle Pin goes to a Digital
Input Pin

# Components - Additional Information


Soil Moisture Sensor

Provides Analog and Digital
Data Pin -> A0 goes to any analog pin for
analog input or D0 to any Digital pin for Digital
Input
NEMA 17 Stepper Motor

Provides precise movement without the
sacrifice of speed or movement range
Requires a stepper motor driver to
properly function
Has external libraries, but can function
without them
DRV 8825 Stepper Motor Driver

Has an output drive capacity of up to
45V, allowing for control of bi-polar
stepper motor, such as NEMA 17.
Placed directly onto the CNC Shield V3
Incremental Encoder

Rotary encoders can rotate 360°
without stopping, whereas
potentiometers can only rotate 3/4
of the circle.
Data pin -> CLK and DT for the rotary
movement and SW for Switch inbuilt

# Mechanical Components - Additional Information

3D Printed Materials

2040 Aluminum Profile
Used for Basic Structure of the
robot
Is connected using T-Nut and Bolt

All Materials made on Tinkercad and
Freecad and uploaded here:-
bit.ly/homefarmer3dprint

T-Nut and Bolts

Keeps stability in between the profiles,
and prevents it from falling apart

Lead Screw, Belt, Pulley, and Trolley

Helps in movement of all axes
Lead Screw allows for precision in the z axis.
Pulley connects to stepper motor and the
opposite end to host the belt, which is
connected to the trolley for movement

LIST OF SOURCES

https://lastminuteengineers.com/ds1307-rtc-arduino-tutorial/https://lastminuteengineers.com/arduino-1602-character-lcd-tutorial/https://www.youtube.com/watch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
https://forum.arduino.cc/t/using-cnc-shield-v3-directly-with-arduino-ide/1022999/2https://www.handsontec.com/dataspecs/cnc-3axis-shield.pdfhttps://www.arduino.cc/ref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 - For designing parts

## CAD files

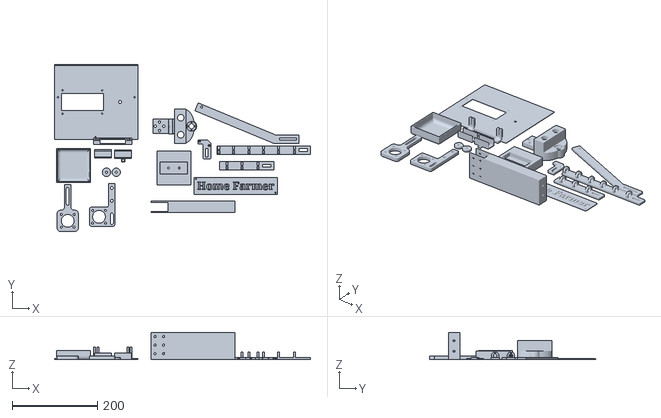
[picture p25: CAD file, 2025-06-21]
3D Printing/2024 (v2.4)/Home Farmer All 3D Printed Parts.stl
601.0 x 392.0 x 64.0

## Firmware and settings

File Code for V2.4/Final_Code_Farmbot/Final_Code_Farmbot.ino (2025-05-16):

/*
* This is the complete explained code for the Home Farmer V2.4
* (Home Farmer V2.4 is the one presented at the WRO 2024 season)
*/

// Defining E_OK (yes) and E_NOK (no) macros because coding habits
#define E_OK 0
#define E_NOK 1

// Including the Servo library and defining a Servo object for the seed picker
#include "Servo.h"
  Servo pick;

// Including more needed libraries
#include <LiquidCrystal_I2C.h>
#include "Arduino.h"
#include "uRTCLib.h"
#include <dht.h>

// Defining some more macros
#define outPin 0
#define watdel 6000
#define afterwatdel 3000

// Defining the RTC ,DHT, and LCD objects
uRTCLib rtc(0x68);
dht DHT;
LiquidCrystal_I2C lcd(0x27, 20, 4);

// Defining the Required Variables
long mois = 0;
char daysOfTheWeek[7][12] = { "Mon", "Tue", "Wed", "Thu", "Fri", "Sat", "Sun" };  // I know the order of the days is wrong
int d, mo, y, h, m, s, AP;
int readData;
int hum, temp;
int counterScreen = 1;
int counter = 0;
int currentStateCLK;
int lastStateCLK;
String currentDir = "";
unsigned long lastButtonPress = 0;
int btnState;
int screen = 1;
int prevcounter = 0;
int diff = 0;
int flag = 0;
int config = 0;
long rtccount = 0;
int prevrtccount = 0;
int dotdiff = 0;

// Function for reading the Rotary Encoder (All the comments written inside this function are not written by me)
void readrotary() {
  // Read the current state of CLK
  //currentStateCLK = digitalRead(CLK);

  currentStateCLK = digitalRead(A2);
  // If last and current state of CLK are different, then pulse occurred
  // React to only 1 state change to avoid double count
  if (currentStateCLK != lastStateCLK && currentStateCLK == 1) {

    // If the DT state is different than the CLK state then
    // the encoder is rotating CCW so decrement


    if (digitalRead(A1) != currentStateCLK) {
      counter--;
      currentDir = "CCW";

    } else {
      // Encoder is rotating CW so increment
      counter++;
      currentDir = "CW";
    }
  }

  // Remember last CLK state
  lastStateCLK = currentStateCLK;
}

// Function to read the button state of the Rotary Encoder and switch the screen accordingly (dunno about the last part)
// (Comments written inside this function are not written by me)
void readbutton(int casen) {
  btnState = digitalRead(A0);
  //If we detect LOW signal, button is pressed
  if (btnState == LOW) {

    //if 50ms have passed since last LOW pulse, it means that the
    //button has been pressed, released and pressed again
    if (millis() - lastButtonPress > 100) {
      switch (casen) {
        case 0:
          screen = 4;
          break;
        case 1:
          screen = 3;
          break;
        case 3:
          screen = 12;
          break;
        case 4:
          screen = 16;
          break;
        case 5:
          screen = 20;
          delay(300);
          lcd.clear();
          break;
        case 7:
          screen = 15;
          break;
        case 8:
          screen = 0;
          break;
        case 9:
          screen = 19;
          break;
        case 10:
          screen = 0;
          break;
      }
      // lcd.clear();
    }

    // Remember last button press event
    lastButtonPress = millis();
  }
}

// Function to update the RTC every time it is called
void readRTC() {
  rtc.refresh();
  d = rtc.day();
  mo = rtc.month();
  y = rtc.year();
  h = rtc.hour();
  m = rtc.minute();
  s = rtc.second();
  if (h > 12) {
    h = h - 12;
    AP = 1;
  } else {
    AP = 0;
  }
}

// Function for the Home Screen code
void homeScreen() {
  // Print the Day
  lcd.clear();
  lcd.setCursor(0, 0);
  if (d > 9) {
    lcd.print(d);
  } else {
    lcd.print("0");
    lcd.print(d);
  }

  // Print the month
  lcd.print("/");
  if (mo > 9) {
    lcd.print(mo);
  } else {
    lcd.print("0");
    lcd.print(mo);
  }

  // Print the year
  lcd.print("/");
  lcd.print(y);

  lcd.print(" ");

  // Print the day
  lcd.print(daysOfTheWeek[rtc.dayOfWeek() - 1]);

  lcd.setCursor(0, 1);

  // Print the time (HH:MM) in 12-hour format
  if (h > 9) {
    lcd.print(h);
  } else {
    lcd.print("0");
    lcd.print(h);
  }
  lcd.print(":");
  if (m > 9) {
    lcd.print(m);
  } else {
    lcd.print("0");
    lcd.print(m);
  }

  lcd.print(" ");

  // Determine AM or PM using the AP boolean
  if (AP == 1)
    lcd.print("PM");
  else
    lcd.print("AM");


  lcd.setCursor(15, 0);

  // Print Humidity
  lcd.print("H:");
  lcd.print(hum);
  lcd.print("%");

  // Print temperature
  lcd.setCursor(15, 1);
  lcd.print("T:");
  lcd.print(temp);
  lcd.print("C");


  lcd.setCursor(5, 2);

  // Print the Title Text
  lcd.print("Home Farmer");

  // Print the Selectable Options
  lcd.setCursor(3, 3);
  lcd.print("Menu");

  lcd.setCursor(13, 3);
  lcd.print("Info");
}

// Function to read the DHT when called
void readDHT() {
  // temperature
  readData = DHT.read11(outPin);
  temp = DHT.temperature;  // Read temperature
  hum = DHT.humidity;      // Read humidity
}

// Update the RTC and DHT every 8 seconds (to avoid lag)
void RTCupdate() {
  rtccount++;
  if (rtccount > 8000) {
    readRTC();
    readDHT();
    screen = 0;
    rtccount = 0;
  }
}

// Shift the screen with the previous screen (encoder to left) and the next screen (encoder to right) parameters
void shiftscreen(int prev, int next) {
  diff = counter - prevcounter;

  if (diff > 0) {
    screen = prev;
  } else if (diff < 0) {
    screen = next;
  } else {
  }
  prevcounter = counter;
}


// Class for Stepper Motor Driving (Basically a whole library)
// Things I don't understand start here
class operate {
public:
  void setPin(int p, int pD);                                        // set pin for stepper mot PWM and direction pin
  void setSpeed(int MotS);                                           // set stepper motor speed - 1 2 3
  void move(int m, int dir);                                         // move by how much,direction , 1- F 0- R,
  int home();                                                        // home the motor
  int getCurrentPos();                                               // get current postion of motor
  int setHoming(int homing, int motspeed, int timeout, int lswPin);  // set homing allowed or not, set motorspeed while homing , set timeout timer value for homing , set pin of limit switch for homing
  int setPosition(long set);                                         // set postion of stepper motor
  int setPositionLimits(long max, long min);                         // set maximum and minimum limits of stepper motor postion
                                                                     // operate() : currpos(0) {}
private:
  long count;             // count for for loop
  int pinDir;             // pin for direction fo motor
  int pin;                // pin for motor PWM
  int lsw;                // limit switch
  int limitSWPin;         // limit switch pin
  long currpos{ 0 };      // current postion of motor value
  int timer;              // timer value
  int timeouttimer;       // timeput timer value for homing
  int MotSpeed;           // mot speed value
  int MotDelay;           // mot delay for PWM
  int homingAllowed;      //  if homing is allowed or not
  int MotSpeedforHoming;  // timeout timer value for homing
  long setPos;            // set postion of motor
  long MinLimit;          // Min limit of postion of motor
  long MaxLimit;          // Max limit of posistin of motor
};


void operate::setPin(int p, int pD) {
  pin = p;
  pinDir = pD;
}

void operate::setSpeed(int MotS) {
  MotDelay = MotS;
}


void operate::move(int m, int dir) {
  if (dir == 1) {
    digitalWrite(pinDir, LOW);
    for (count = 0; count < m; count++) {
      digitalWrite(pin, HIGH);
      delayMicroseconds(MotDelay);
      digitalWrite(pin, LOW);
      delayMicroseconds(MotDelay);
      currpos++;
    }
  } else {
    digitalWrite(pinDir, HIGH);
    for (count = 0; count < m; count++) {
      digitalWrite(pin, HIGH);
      delayMicroseconds(MotDelay);
      digitalWrite(pin, LOW);
      delayMicroseconds(MotDelay);
      currpos--;
    }
  }
}

int operate::home() {
  digitalWrite(pinDir, HIGH);
  lsw = digitalRead(limitSWPin);
  while (lsw == HIGH && homingAllowed == E_OK) {
    lsw = digitalRead(limitSWPin);
    digitalWrite(pin, HIGH);
    delayMicroseconds(MotSpeedforHoming);
    digitalWrite(pin, LOW);
    delayMicroseconds(MotSpeedforHoming);
  }
  currpos = 0;
  return E_OK;
}

int operate::getCurrentPos() {
  return currpos;
}

int operate::setHoming(int homing, int motspeed, int timeout, int lswPin) {
  MotSpeedforHoming = motspeed;
  timeouttimer = timeout;
  limitSWPin = lswPin;
  if (homing == E_OK) {
    homingAllowed = E_OK;
    return E_OK;
  } else {
    homingAllowed = E_NOK;
    return E_NOK;
  }
}

int operate::setPosition(long set) {
  long diff;
  if (set > currpos && set >= MinLimit && set <= MaxLimit) {
    diff = set - currpos;
    digitalWrite(pinDir, LOW);
    for (count = 0; count < diff; count++) {
      digitalWrite(pin, HIGH);
      delayMicroseconds(MotDelay);
      digitalWrite(pin, LOW);
      delayMicroseconds(MotDelay);
      currpos++;
    }
    return E_OK;
  } else if (set < currpos && set >= MinLimit && set <= MaxLimit) {
    diff = currpos - set;
    digitalWrite(pinDir, HIGH);
    for (count = 0; count < diff; count++) {
      digitalWrite(pin, HIGH);
      delayMicroseconds(MotDelay);
      digitalWrite(pin, LOW);
      delayMicroseconds(MotDelay);
      currpos--;
    }
    return E_OK;
  } else if (set == currpos && set >= MinLimit && set <= MaxLimit) {
    return E_OK;
  } else {
    return E_NOK;
  }
}



int operate::setPositionLimits(long max, long min) {
  MinLimit = min;
  MaxLimit = max;
  return E_OK;
}

// Things I don't understand end here

// Defining 3 stepper motor (operate) objects from the class
operate mot_x;
operate mot_y;
operate mot_z;

// Function to pick the seed and plant it (Not sure tbh)
void seedpickarea() {
  mot_z.setPosition(30000);
  delay(100);
  pick.write(100);
  delay(100);
  mot_y.setPosition(1000);
  delay(100);
  mot_x.setPosition(11250);
  delay(100);
  mot_z.setPosition(62000);
  delay(100);
  pick.write(40);
  delay(300);
  mot_z.setPosition(30000);
  delay(100);
}

// Drop the seed at specified coordinates
void seedplant(long x, long y) {
  mot_y.setPosition(y);
  delay(100);
  mot_x.setPosition(x);
  delay(100);
  mot_z.setPosition(55000);
  delay(100);
  pick.write(100);
  delay(500);
}

// Use the 2 functions above to place the seeds at set locations (for testing only)
void seeding() {
  seedpickarea();
  seedplant(500, 4000);

  seedpickarea();
  seedplant(500, 12000);

  seedpickarea();
  seedplant(8000, 4000);

  seedpickarea();
  seedplant(8000, 12000);
}

// Water the coordinates at which the seeds are placed
void watering() {
  seedplant(500, 4000);
  digitalWrite(12, HIGH);
  delay(watdel);
  digitalWrite(12, LOW);
  delay(afterwatdel);

  seedplant(500, 12000);
  digitalWrite(12, HIGH);
  delay(watdel);
  digitalWrite(12, LOW);
  delay(afterwatdel);

  seedplant(8000, 4000);
  digitalWrite(12, HIGH);
  delay(watdel);
  digitalWrite(12, LOW);
  delay(afterwatdel);

  seedplant(8000, 12000);
  digitalWrite(12, HIGH);
  delay(watdel);
  digitalWrite(12, LOW);
  delay(afterwatdel);
}

// FINALLY we have the void setup
// Some of the comments written inside are mine
void setup() {
  // Define pins to the different components (idk which pin is which component)
  pick.attach(13); // Servo
  pinMode(2, OUTPUT);
  pinMode(3, OUTPUT);
  pinMode(4, OUTPUT);
  pinMode(9, INPUT_PULLUP);  // limit switch
  pinMode(10, INPUT_PULLUP);
  pinMode(11, INPUT_PULLUP);
  pinMode(5, OUTPUT);  // direction
  pinMode(6, OUTPUT);
  pinMode(7, OUTPUT);
  pinMode(12, OUTPUT);
  pinMode(8, OUTPUT);
  digitalWrite(8, LOW);
  digitalWrite(12, LOW);

  // Define all the other components for LCD and Rotary , DHT, RTC

  // RTC
  URTCLIB_WIRE.begin();
  //rtc.set(0, 32, 11, 7, 24, 8, 24);
  //  rtc.set(second, minute, hour, dayOfWeek, dayOfMonth, month, year)
  // set day of week (1=Monday, 7=Sunday)

  //LCD
  lcd.init();
  lcd.clear();
  lcd.backlight();  // Make sure backlight is on

  // Read the initial state of CLK
  lastStateCLK = analogRead(A2);
  if (lastStateCLK > 512)
    lastStateCLK = 1;
  else
    lastStateCLK = 0;

  // Invoke the functions to update both the modules
  readRTC();
  readDHT();


  // Define motors
  mot_x.setPin(2, 5);  // x
  mot_y.setPin(3, 6);  // y
  mot_z.setPin(4, 7);  // z
  // Set Motor speeds
  mot_x.setSpeed(160);
  mot_y.setSpeed(160);
  mot_z.setSpeed(35);
  // Set Homing for All the motors
  mot_x.setHoming(E_OK, 160, 10000, 9);
  mot_y.setHoming(E_OK, 160, 10000, 10);
  mot_z.setHoming(E_OK, 35, 10000, 11);
  // Set position limits for all the motors
  mot_x.setPositionLimits(12000, 0);
  mot_y.setPositionLimits(14000, 0);
  mot_z.setPositionLimits(65000, 0); // Yes the 65000 is not a typo, its a motor attached to a lead screw

  // Print the Initializing Screen on the LCD
  lcd.clear();
  lcd.setCursor(5, 0);
  lcd.print("Home Farmer");
  lcd.setCursor(7, 1);
  lcd.print("Homing...");
  lcd.setCursor(0, 2);
  lcd.print("Please Wait...");
  lcd.setCursor(0, 3);
  lcd.print("[-");
  lcd.setCursor(16, 3);
  lcd.print("]");
  lcd.setCursor(17, 3);
  lcd.print(" 1%");
  delay(3000);

  // Perform on-start homing
  mot_z.home();
  lcd.setCursor(17, 3);
  lcd.print("33%");
  lcd.setCursor(2, 3);
  lcd.print("----");
  mot_x.home();
  lcd.setCursor(17, 3);
  lcd.print("66%");
  lcd.setCursor(6, 3);
  lcd.print("----");
  mot_y.home();
  lcd.setCursor(17, 3);
  lcd.print("99%");
  lcd.setCursor(10, 3);
  lcd.print("----");
  delay(1000);
  lcd.setCursor(0, 2);
  lcd.print("    Homing Done!!!");
  lcd.setCursor(0, 1);
  lcd.print("                    ");
  lcd.setCursor(0, 3);
  lcd.print("                    ");
  pick.write(100);
  delay(2000);
  homeScreen();
}

void loop() {
  // Define the screens and the role of the Rotary Encoder
  switch (screen) {
    case 0: // Home Screen (is without the selector arrow)
      homeScreen();
      rtccount = 0;
      screen = 1; // Directly shifts to the Home Screen 2
      break;
    case 1: // Home Screen with Selector on "Menu"
      readrotary();
      readbutton(0);
      RTCupdate();
      lcd.setCursor(2, 3);
      lcd.print(">");
      lcd.setCursor(12, 3);
      lcd.print(" ");
      shiftscreen(2, 1);
      break;
    case 2: // Home Screen with Selector on "Info"
      readrotary();
      readbutton(1);
      RTCupdate();
      lcd.setCursor(2, 3);
      lcd.print(" ");
      lcd.setCursor(12, 3);
      lcd.print(">");
      shiftscreen(1, 2);
      break;
    case 3: // Info Screen (When user selects "Info" on the Home screen)
      lcd.clear();
      lcd.setCursor(2, 0);
      lcd.print("Home Farmer V2.4");
      lcd.setCursor(4, 1);
      lcd.print("A Project By");
      lcd.setCursor(1, 2);
      lcd.print("Vihaan & Yogeshwar");
      lcd.setCursor(2, 3);
      lcd.print("Mentor: Malhar A");
      rtccount = 0;
      delay(7000);
      screen = 0;
      break;
    case 4: // Plant seed screen under menu (When user clicks on "Menu" on the Home screen or when the user turns rotary to the left from "Water Plants" screen)
      lcd.clear();
      lcd.setCursor(15, 0);
      if (h > 9) {
        lcd.print(h);
      } else {
        lcd.print("0");
        lcd.print(h);
      }
      lcd.print(":");
      if (m > 9) {
        lcd.print(m);
      } else {
        lcd.print("0");
        lcd.print(m);
      }
      lcd.setCursor(0, 0);
      if (d > 9) {
        lcd.print(d);
      } else {
        lcd.print("0");
        lcd.print(d);
      }

      lcd.print("/");
      if (mo > 9) {
        lcd.print(mo);
      } else {
        lcd.print("0");
        lcd.print(mo);
      }
      lcd.setCursor(9, 0);
      lcd.print(daysOfTheWeek[rtc.dayOfWeek() - 1]);

      lcd.setCursor(0, 3);
      lcd.print(" ");
      lcd.setCursor(19, 3);
      lcd.print(">");

      lcd.setCursor(7, 1);
      lcd.print("[Menu]");

      lcd.setCursor(2, 2);
      lcd.print("-| Plant Seed |-");
      rtccount = 0;
      screen = 5;
      break;
    case 5: // Read the Rotary
      readrotary();
      readbutton(3);
      RTCupdate();
      shiftscreen(5, 6);
      break;
    case 6: // Water Plants screen under Menu (When user moves the encoder to the right when on "Plant Seed" screen or to the left when on "Parameters" screen)
      lcd.setCursor(2, 2);
      lcd.print("-|Water Plants|-");
      lcd.setCursor(0, 3);
      lcd.print("<");
      rtccount = 0;
      screen = 7;
      break;
    case 7: // Read the Rotary
      readrotary();
      readbutton(4);
      RTCupdate();
      shiftscreen(4, 8);
      break;
    case 8: // Parameters screen under Menu (When user moves the encoder to the right when on "Water Plants" screen or left from the "Exit" screen)
      lcd.setCursor(1, 2);
      lcd.print("                  ");
      lcd.setCursor(2, 2);
      lcd.print("-| Parameters |-");
      lcd.setCursor(0, 3);
      lcd.print("<");
      lcd.setCursor(19, 3);
      lcd.print(">");
      rtccount = 0;
      screen = 9;
      break;
    case 9: // Read the rotary
      readrotary();
      readbutton(5);
      RTCupdate();
      shiftscreen(6, 10);
      break;
    case 10: // Exit screen under Menu (When user moves the encoder to the right when on "Parameters screen")
      lcd.setCursor(1, 2);
      lcd.print("                  ");
      lcd.setCursor(6, 2);
      lcd.print("-| Exit |-");
      lcd.setCursor(0, 3);
      lcd.print("<");
      lcd.setCursor(19, 3);
      lcd.print(" ");
      rtccount = 0;
      screen = 11;
      break;
    case 11: // Read the Rotary
      readrotary();
      readbutton(6);
      RTCupdate();
      shiftscreen(8, 10);
      break;
    case 12: // Plant Seeds Now screen when arrow is on Yes (Shown when the user clicks the rotary button when on the Plant Seeds screen)
      lcd.clear();
      lcd.setCursor(15, 0);
      if (h > 9) {
        lcd.print(h);
      } else {
        lcd.print("0");
        lcd.print(h);
      }
      lcd.print(":");
      if (m > 9) {
        lcd.print(m);
      } else {
        lcd.print("0");
        lcd.print(m);
      }
      lcd.setCursor(0, 0);
      if (d > 9) {
        lcd.print(d);
      } else {
        lcd.print("0");
        lcd.print(d);
      }

      lcd.print("/");
      if (mo > 9) {
        lcd.print(mo);
      } else {
        lcd.print("0");
        lcd.print(mo);
      }
      lcd.setCursor(9, 0);
      lcd.print(daysOfTheWeek[rtc.dayOfWeek() - 1]);

      lcd.setCursor(2, 1);
      lcd.print("-| Plant Seed |-");

      lcd.setCursor(2, 2);
      lcd.print("Plant seeds Now?");

      lcd.setCursor(2, 3);
      lcd.print("Yes");

      lcd.setCursor(16, 3);
      lcd.print("No");

      lcd.setCursor(1, 3);
      lcd.print(">");

      lcd.setCursor(15, 3);
      lcd.print(" ");
      screen = 13;
      rtccount = 0;
      break;
    case 13: // Read the rotary
      readrotary();
      readbutton(7);
      RTCupdate();
      shiftscreen(12, 14);
      break;
    case 14: // Plant Seeds Now screen when the arrow is on No (Triggered when the user turns encoder to the right)
      lcd.setCursor(1, 3);
      lcd.print(" ");

      lcd.setCursor(15, 3);
      lcd.print(">");
      readrotary();
      readbutton(8);
      RTCupdate();
      shiftscreen(14, 12);
      break;
    case 15: // Seed Planting Progress screen (Triggered when user clicks on Yes in the Plant Seeds Now screen)
      lcd.clear();
      lcd.setCursor(15, 0);
      if (h > 9) {
        lcd.print(h);
      } else {
        lcd.print("0");
        lcd.print(h);
      }
      lcd.print(":");
      if (m > 9) {
        lcd.print(m);
      } else {
        lcd.print("0");
        lcd.print(m);
      }
      lcd.setCursor(0, 0);
      if (d > 9) {
        lcd.print(d);
      } else {
        lcd.print("0");
        lcd.print(d);
      }

      lcd.print("/");
      if (mo > 9) {
        lcd.print(mo);
      } else {
        lcd.print("0");
        lcd.print(mo);
      }
      lcd.setCursor(9, 0);
      lcd.print(daysOfTheWeek[rtc.dayOfWeek() - 1]);

      lcd.setCursor(2, 2);
      lcd.print("Planting Seeds...");
      lcd.setCursor(2, 3);
      lcd.print("Please wait...");
      seeding();
      lcd.clear();
      lcd.setCursor(1, 0);
      lcd.print("Seeding Successful!");
      lcd.setCursor(7, 1);
      lcd.print("Homing...");
      lcd.setCursor(0, 2);
      lcd.print("Please Wait...");
      lcd.setCursor(0, 3);
      lcd.print("[-");
      lcd.setCursor(16, 3);
      lcd.print("]");
      lcd.setCursor(17, 3);
      lcd.print(" 1%");
      mot_z.home();
      lcd.setCursor(17, 3);
      lcd.print("33%");
      lcd.setCursor(2, 3);
      lcd.print("----");
      mot_x.home();
      lcd.setCursor(17, 3);
      lcd.print("66%");
      lcd.setCursor(6, 3);
      lcd.print("----");
      mot_y.home();
      lcd.setCursor(17, 3);
      lcd.print("99%");
      lcd.setCursor(10, 3);
      lcd.print("----");
      delay(1000);
      lcd.setCursor(0, 2);
      lcd.print("    Homing Done!!!");
      lcd.setCursor(0, 1);
      lcd.print("                    ");
      lcd.setCursor(0, 3);
      lcd.print("                    ");
      pick.write(100);
      delay(2000);
      screen = 0;
      break;
    case 16: // Water Plants Now screen without arrows (Triggered when the user clicks the encoder button when on the Water Plants screen)
      delay(300);
      lcd.clear();
      lcd.setCursor(15, 0);
      if (h > 9) {
        lcd.print(h);
      } else {
        lcd.print("0");
        lcd.print(h);
      }
      lcd.print(":");
      if (m > 9) {
        lcd.print(m);
      } else {
        lcd.print("0");
        lcd.print(m);
      }
      lcd.setCursor(0, 0);
      if (d > 9) {
        lcd.print(d);
      } else {
        lcd.print("0");
        lcd.print(d);
      }
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

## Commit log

2025-06-21 Added 3D Print file
    [Home Farmer All 3D Printed Parts.stl]
2025-06-21 (Website) Fixed redirection for print files
2025-07-29 Fixed screen saying 'Water Planting...'
    Replaced 'Water Planting... with 'Watering Plants...'
    [main.ino]
2025-07-30 Fixed Y axis offset and removed formula text file
    [main.ino]
2025-08-25 Added Alexa Integration code for Arduino and Raspberry Pi
    Used serial to integrate Home Farmer with Amazon Alexa to give commands such as Plant Seeds or Water Plants
2025-08-29 Added the first Raspberry Pi Dashboard
2025-09-05 Fixed DHT on Home Screen
    [main.ino]
